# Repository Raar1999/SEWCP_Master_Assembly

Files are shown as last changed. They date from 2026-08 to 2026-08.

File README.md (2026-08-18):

# AIEF — Agent-Driven Semiconductor CAD Engineering

**An engineering pipeline that converts governed semiconductor-equipment requirements into
parametric Fusion 360 designs, verifies the resulting geometry against the requirement from the
model Fusion actually built, and iterates through failure-recovery loops before release.**

The demonstration hardware is **SEWCP** — a 300 mm bipolar electrostatic chuck pedestal for
RF-biased plasma process equipment.

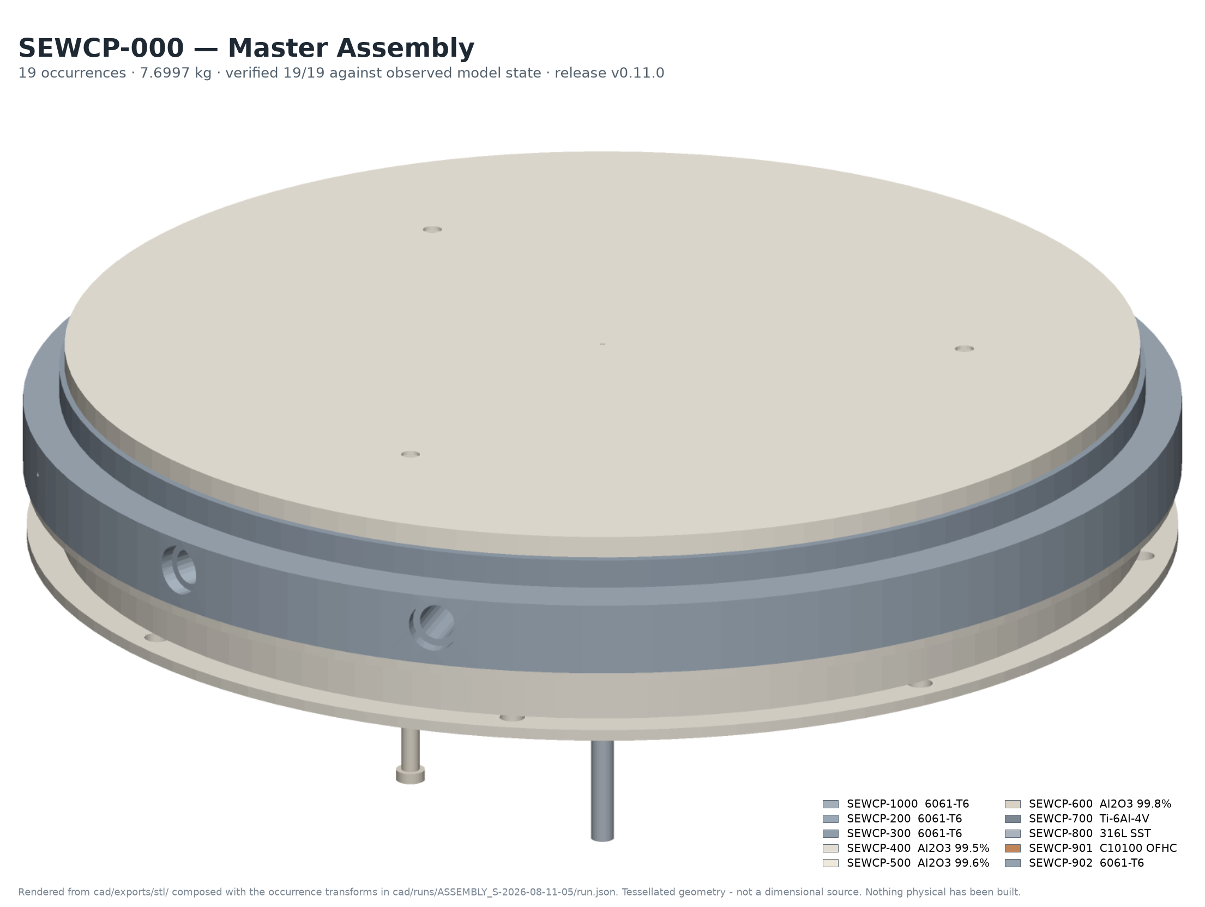
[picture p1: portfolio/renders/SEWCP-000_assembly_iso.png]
SEWCP-000 master assembly — shaded isometric of the 19-occurrence pedestal


<sub>*SEWCP-000 master assembly. Rendered from the released STL exports composed with the
occurrence transforms in `cad/runs/ASSEMBLY_S-2026-08-11-05/run.json` — every placement
reconciled against the bounding box Fusion actually observed before it was drawn. Tessellated
geometry, not a dimensional source.*</sub>

| | | | |
|---|---|---|---|
| **9** components specified | **10** part designs verified | **19** assembly occurrences | **19 / 19** system verification |
| **11** drawings / **14** sheets | **79** dimensions, **0** unsourced | **61** deliverables, digest-registered | **895** tests pass |
| **36** CAD runs tracked — **18 of them failures** | **5** independent QA rounds, **4** `NOT CLEARED` | **`v0.11.0`** released | **0 of 91** hardware requirements physically verified |

> **Read this before anything else.** The digital release is complete and reproduces from a clean
> clone. **Nothing physical has been built or measured**, and one defect is open against the
> design itself — `ECR-D-016`, the Support Ring isolation joint does not close. **Do not build to
> this baseline.** Details in [Physical qualification boundary](#physical-qualification-boundary).

**Start here:** [Recruiter overview](docs/RECRUITER_OVERVIEW.md) ·
[Architecture](docs/ARCHITECTURE.md) · [How it failed and recovered](docs/FAILURE_RECOVERY.md) ·
[Verification](docs/VERIFICATION.md) · [Independent QA](docs/QA.md)

---

## What I built

- A **Fusion 360 add-in and file-queue protocol** — 32 operations — that drives the modeller and
  reports back **what it observed**, not that the call succeeded. Fusion has no external
  automation API; code inside its own process is the only supported route.
- An **observation-based verification layer**: three independent verifiers (geometry, interface,
  constraint) that read the live model and score it against requirement-derived acceptance
  criteria. **No verifier reads whether the CAD command executed.**
- A **bounded failure-recovery loop** with root-cause classification by owning layer,
  digest-enforced no-blind-retry, capped attempts, and a document lifecycle where a design is
  **saved only on verified PASS**.
- **AIEF**, the governance framework around it: 13 laws, 12 role contracts, 25 validation rules,
  a six-stage compiler, a hash-chained ledger, and 8 standing checks that *compute* the
  properties the documents claim.
- The **SEWCP engineering specification** — Volumes 00–09, 137 numbered component requirements,
  frozen — and the CAD, drawings, BOM and analyses produced under it.

## The core idea

> **A CAD operation succeeding is not evidence that it worked.**

`extrude(...)` returning OK means Fusion accepted the operation. It says nothing about whether
the resulting solid satisfies the requirement. So three facts are kept apart and never merged:

| Fact | Reported by |
|---|---|
| An agent **requested** an operation | the orchestrator |
| Fusion **performed** it | Fusion, about its own work |
| The model **satisfies** the requirement | an independent verifier reading observed state |

Only the third is acceptance. Everything else is a claim.

## How it works

```
  spec/**  frozen, hash-registered
     │  requirements → design solution → operation sequence
     ▼
  CAD bridge  ──── file queue ────►  Fusion 360 + AIEF_CAD_Bridge add-in
     ▲                                          │
     │                           OBSERVED model state — extents, volume, mass,
     │                           material, parameters, sketches, planes, features
     │                                          ▼
     │                              independent verification
     │                               ╱                    ╲
     └── repair ◄── diagnose ◄── FAIL                    PASS ──► save · export
         (bounded)                  ╲                              draw · release
                                     └─► escalate (ECR)
```

Diagram: [`docs/assets/architecture.svg`](docs/assets/architecture.svg) · full detail:
[`docs/ARCHITECTURE.md`](docs/ARCHITECTURE.md).

## SEWCP demonstration

| | |
|---|---|
| Wafer | 300 mm × 775 µm |
| Chucking | Coulombic, bipolar, ±500 to ±2000 VDC |
| Wafer plane above Datum A | 55.920 ± 0.150 mm |
| Wafer temperature | 20–150 °C, ±2.0 °C across Ø300 |
| Coolant | 4 L/min, Re ≈ 8,300, 3 kW capacity |
| Heater | 2 zones, 2000 W |
| RF bias | 13.56 MHz, ≤ 1000 W |

Nine specified components — cooling plate, heater plate, ceramic support ring, electrostatic
chuck, lift pins, alignment pins, vacuum port, RF feedthrough bracket, temperature sensor bracket
— realised as ten part designs and one master assembly. The Base Plate `SEWCP-100` is frozen and
out of scope.

## Results

| Item | Result | Computed by |
|---|---|---|
| Gate `LC-M04-EXIT` | **PASS** C1–C7 | `python -m aief_gate` |
| Feature clearance, `spec/00` §3.2 | **PASS**, pair by pair | `python -m aief_clearance` |
| Parameter master | **105** derived | `python -m aief_params check` |
| Approval chains | **CLEAN** | `python -m aief_approval verify` |
| Deliverables | **61 registered, 61 reproduce, 0 unregistered** | `python -m aief_deliverables` |
| Freeze registry | **31 of 31 verify** | `V-24` |
| Boot step B2a, core integrity | **75 / 75**, independently recomputed | `python -m aief_stage6` |
| System interfaces | **12 / 12** | `cad/runs/SYSTEM_INTERFACES.json` |
| Assembly | **19 occurrences**, PASS, 7.6997 kg | `cad/runs/ASSEMBLY_S-2026-08-11-05/` |
| Final system verification | **19 / 19** | `cad/runs/FINAL_SYSTEM_VERIFICATION.json` |
| Tests | **895 local · 843 from a clean clone**, 0 fail | `pytest tests/` |

Every figure above is measured at the release commit `cad6ced6`. Two standing checks exit non-zero
**and are meant to**: `aief_analysis`, because `ECR-D-016` does not close, and `aief_exec check`,
which reports three open exec-layer conditions of its own. A check reporting PASS on an open
defect would itself be the defect.

> **This file is a governed deliverable, and rewriting it is a recorded act.** `README.md` is
> pinned by DC-1 in a result record, so the portfolio rewrite moved its digest and `X-06` — the
> drift detector — reported the record STALE. That is the mechanism working. It was answered the
> way the architecture prescribes: **by supersession, never by mutation.** `R-031` republishes
> the digest, seals `R-030` at the state it now stands at, and `R-030` itself is preserved.
> [`docs/DOCUMENTATION_FINDINGS.md`](docs/DOCUMENTATION_FINDINGS.md) §6.

## Engineering failure → recovery → verification

Two M6 hanger taps in the cooling plate. **Eight operations dispatched, eight executed, zero
Fusion errors.** A clean run by any normal measure of CAD automation.

It failed:

```
ACC-VOL   body:CP_BODY.volume_mm3   requirement CP-HANGER-TAP
expected  1479108.9
observed  1479282.6100163697
detail    delta 173.71 exceeds tolerance 1
```

The taps were breaking into the outer thermal-choke slots, so they removed 504.8 mm³ instead of
678.6 mm³. The bounded loop re-dispatched twice, made no progress, and **escalated rather than
degrading into a pass**. The failure disposition tried to discard the document and was *refused
by contract* — `a saved design is never discarded by recovery` — and reverted instead.

Then the finding that justifies the whole architecture: a feasibility sweep proved **no compliant
position existed anywhere inside the placement window the specification itself had given.** The
requirement was wrong, not the model. Corrected placement ruled, cleared against nine
neighbouring features, specification rows re-issued under approval, re-run — **PASS on the first
attempt, observed volume within 0.04 mm³**, and only then was the document saved.

Elapsed: **5 min 13 s**. Full trace, plus a second case:
[`docs/FAILURE_RECOVERY.md`](docs/FAILURE_RECOVERY.md).

The repository tracks **36 CAD runs, 18 PASS and 18 FAIL.** The failures are committed on
purpose — a record containing only successes has not shown you its verification working.

## Independent QA

**LAW-05: no role verifies its own output.** Independence is supplied by a **cold-context
session** that reconstructs every fact from the repository, recomputes without importing the code
under audit, writes no repository file, and returns a verdict the repairing session did not
choose.

Five rounds ran against this release. **Four returned `NOT CLEARED`**, and each found a real
defect in a repair that looked complete — including a ruling enforced only on a non-canonical
code path, which survived all 846 tests, and a check written to end a recurring defect that did
not catch that defect.

Two of their recomputations contradicted the repository and were right: the deliverables were not
byte-identical to the generation root, and the suite did not pass from a clean clone.

And the finding that is not closed: **four consecutive repair sessions each introduced a defect
of the class they were repairing** (`OI-V-17`). Recorded, not quietly repaired.

[`docs/QA.md`](docs/QA.md).

## Engineering deliverables

61 files, 4,995,097 bytes, every digest registered in [`cad/DELIVERABLES.md`](cad/DELIVERABLES.md)
and checked **both directions**.

| | |
|---|---|
| Neutral geometry | **11 STEP** — 10 parts + the master assembly — `cad/exports/step/` |
| Tessellated | **10 STL** — `cad/exports/stl/` |
| Drawings | **11 documents / 14 sheets** — SVG + PDF, with a provenance sidecar naming the source of **every one of 79 dimensions** — `drawings/` |
| BOM | indentured Rev A, cross-checked four ways — `cad/bom/` |

The parametric `.f3d` is deliberately **not** here: `SEDEP-PMP-002` §3.1 places the parametric
source of record in Fusion cloud versioning and git holds the neutral record.
[`docs/DELIVERABLES.md`](docs/DELIVERABLES.md).

## Architecture

| Layer | What it holds |
|---|---|
| **Specification** | `spec/` — Volumes 00–09, frozen and hash-registered; 137 numbered component requirements |
| **Agents** | `src/aief_cad/agents.py` + `.ai/core/agents/` — domain-bounded contributions; 12 role contracts |
| **CAD bridge** | `src/aief_cad/bridge/` + `fusion_addin/AIEF_CAD_Bridge/` — file-queue transport, 32 operations |
| **Observation** | `src/aief_cad/observe.py` — *absence is represented as absence* |
| **Verification** | `src/aief_cad/verify/` — geometry · interface · constraint |
| **Recovery** | `src/aief_cad/loop.py` — classify, repair bounded, or escalate |
| **Framework** | `framework/` + `.ai/` — laws, gates, approvals, hash-chained ledger, six-stage compiler |
| **Standing checks** | `src/` — eight packages that compute what the documents claim |

[`docs/ARCHITECTURE.md`](docs/ARCHITECTURE.md).

## Repository structure

```
spec/            frozen engineering specification, Volumes 00–09
implementation/  per-component requirement packages (the executable input)
src/             aief_cad, aief_gate, aief_clearance, aief_params, aief_approval,
                 aief_deliverables, aief_register, aief_analysis, aief_exec,
                 aief_stage6, aief_draw, sedep
fusion_addin/    AIEF_CAD_Bridge — the Fusion 360 add-in
cad/             runs (tracked evidence, failures included), exports, bom, bridge
drawings/        generator, definitions, released SVG + PDF + provenance sidecars
analysis/        tolerance stack, thermal, structural, electrical/RF, flow
framework/  .ai/ AIEF — laws, roles, gates, ledger, validation, compiler output
tests/           895 tests
docs/            portfolio and presentation layer (this pass)
```

## Reproducing the system

```bash
git clone https://github.com/Raar1999/SEWCP_Master_Assembly.git
cd SEWCP_Master_Assembly
python -m venv .venv && . .venv/Scripts/activate     # Windows; bin/activate on POSIX
pip install -r requirements.txt

PYTHONPATH=src python -m aief_gate            # LC-M04 CAD-READY: YES              exit 0
PYTHONPATH=src python -m aief_clearance       # CLEARANCE OK                       exit 0
PYTHONPATH=src python -m aief_params check    # PARAMETERS OK  105                 exit 0
PYTHONPATH=src python -m aief_approval verify # APPROVAL CHAINS OK                 exit 0
PYTHONPATH=src python -m aief_deliverables    # 61 registered, 61 reproduce        exit 0
PYTHONPATH=src python -m aief_register        # REGISTERS OK                       exit 0
PYTHONPATH=src python -m pytest tests/ -q     # 843 passed, 52 skipped, 0 failed
PYTHONPATH=src python -m aief_analysis        # 4 of 5 FAIL — ECR-D-016            exit 1
```

**These are the numbers a clone actually produces**, measured by cloning this repository from
GitHub and running the battery against it — not the numbers from the author's machine.

The 52 skips measure token budgets through two normative tokenizer families whose artifacts are
third-party binaries and are not tracked. Nothing estimates in their absence — the governing rule
makes absence **block** rather than estimate — so they skip rather than guess. Provision both in
`build/stage6/tokenizer_artifacts/` and the suite runs **894 passed, 1 skipped**; the last skip
needs `build/stage6/detcheck/`, which is gitignored and which no code here creates, so it is
unreachable from a clone by any route.

| Family | File | Raw-octet SHA-256 pinned in `core/MANIFEST.lock` |
|---|---|---|
| TF-1 | `cl100k_base.tiktoken` | `223921b76ee99bde995b7ff738513eef100fb51d18c93597a113bcffe865b2a7` |
| TF-2 | `spiece.model` (T5 SentencePiece) | `d60acb128cf7b7f2536e8f38a5b18a05535c9e14c7a355904270e15b0945ea86` |

With a sibling `TRUST_ON_FIRST_USE.json` present, **a digest mismatch is a loud failure and the
measurement is refused** — never a silent re-pin.

**This reproducibility gap was itself a defect, and it was found the only way it could be.** These
tests once *failed* on a clone while passing at the desk, so the README claimed a reproducibility
that had never been tested from outside. Recorded as `OI-V-16`; the `validate` workflow now runs
the battery on GitHub's runners, where there is no author's machine to be lucky on.

**What a clone cannot reproduce at all:** the Fusion designs live in Autodesk cloud versioning, so
regenerating `cad/` needs Fusion 360 with the add-in installed. Everything else — every gate,
every digest, the drawing set, the BOM and the whole test suite — runs offline.

## Physical qualification boundary

**This repository is a design and process artifact, not a qualified product.**

| | |
|---|---|
| Numbered component requirements | **137** |
| Desk-dischargeable — design, drawing, analysis, calculation | **46** |
| **Hardware required** | **91** |
| **Verified by physical evidence today** | **0** |

No article has been built. Nothing has been measured. The four mass figures are labelled
`MODEL-PREDICTED`, never verified — the declared method is *Scale*, and a scale needs a part. The
record is [`PVR-001`](.ai/project/verification/PVR-001_Physical_Verification_Record_And_Test_Matrix.md),
and it contains **no test result**.

A model establishes geometry and the properties that follow from geometry and a density. It
establishes **nothing** about pressure drop, heat transfer coefficient, leak rate, temperature
uniformity, contact resistance, inductance, particle generation, outgassing, cycle life,
dielectric strength or dechuck behaviour.

**And one defect is open against the design itself.** Filing the creepage/clearance trace that an
open item recorded as owed found that
[**the Support Ring isolation joint does not close**](.ai/project/ecr/ECR-D-016_Support_Ring_Isolation_Joint_Does_Not_Close.md):

| | Required | Computed |
|---|---|---|
| `SR-04` clearance | ≥ 12.00 mm | **8.50 mm** — the greatest any hardware choice can offer |
| `SR-03` creepage | ≥ 20.00 mm | **14.00 mm** as modelled; 17.42 mm at best |
| `SR-02` shunt impedance at 13.56 MHz | ≥ 400 Ω | **353.94 Ω** |

One root cause: two sections of `spec/03` compute a flange gap as empty while a third puts a
6.00 mm grounded ring inside it. It is ruled, its remedy is computed, and it is **deliberately not
implemented here**, because implementing it is a specification re-baseline.
**Do not build to this baseline.**

## Release

| | |
|---|---|
| Release | **`v0.11.0`** — CAD and software complete |
| Commit | `cad6ced6`, annotated tag `v0.11.0`. **Local history diverges from `origin` by design** — see below |
| History | **Sanitized `2026-08-18`** under `ECR-D-018`: a local account name was removed from ten tracked failure records before publication. Pre-rewrite hashes resolve at [`.ai/project/HISTORY_REMAP.md`](.ai/project/HISTORY_REMAP.md). `origin/main` still stands at the pre-rewrite `f8ff028` pending an owner force-update |
| Engineering baseline | SEWCP Rev A, Volumes 00–09 — **FROZEN** |
| Framework | AIEF 1.0.0 — **FROZEN**, fifteen amendments |
| Hardware build | **BLOCKED** by `ECR-D-016` pending a Rev B baseline revision |
| Physical qualification | **NOT STARTED** |

Everything open is at [`.ai/project/OPEN_ITEMS.md`](.ai/project/OPEN_ITEMS.md) with the full record
at [`OPEN_ITEMS_REGISTER.md`](.ai/project/OPEN_ITEMS_REGISTER.md). Nothing is hidden there,
including the failures. [`docs/RELEASE.md`](docs/RELEASE.md) ·
[`CHANGELOG.md`](CHANGELOG.md).

## Navigating

| If you want to… | Go to |
|---|---|
| Understand the project in two pages | [`docs/RECRUITER_OVERVIEW.md`](docs/RECRUITER_OVERVIEW.md) |
| Work in this repository | [`ENGINEERING.md`](ENGINEERING.md) → [`.ai/BOOT.md`](.ai/BOOT.md) |
| Read the engineering baseline | [`spec/README.md`](spec/README.md) |
| Understand datums, budgets, design rules | [`spec/00_…Architecture_and_Interface_Control.md`](spec/00_SEWCP-ENG-001_Architecture_and_Interface_Control.md) |
| See engineering decisions and their alternatives | [`.ai/project/decisions/`](.ai/project/decisions/) |
| See what only hardware can settle | [`PVR-001`](.ai/project/verification/PVR-001_Physical_Verification_Record_And_Test_Matrix.md) |
| Find any document | [`INDEX.md`](INDEX.md) |
| Contribute | [`CONTRIBUTING.md`](CONTRIBUTING.md) |

## Licence

**`MIT AND CC-BY-4.0`** — dual-licensed, and which licence applies to a file is determined by its
path and by nothing else. **MIT** for software (`src/`, `tests/`, `scripts/`, `fusion_addin/`,
`drawings/defs/`, `cad/scripts/`, `*.py`); **CC-BY-4.0** for documents, engineering artifacts and
generated design data (`spec/`, `program/`, and the remaining document trees). Both full texts are
embedded so the licence survives without a network. §3 states expressly that **no patent and no
trademark licence is granted, and that the design is not qualified hardware.**
[`LICENSE`](LICENSE) is authoritative.

## Provenance

The engineering work in this repository — specification, CAD, drawings, analysis, the framework
and its tooling — was produced by an AI agent under human owner authority, with decision authority
delegated for specified runs and every delegated decision recorded as such in
[`.ai/project/decisions/`](.ai/project/decisions/). Human approvals and delegated decisions are
distinguished everywhere they appear, and **a delegated decision is never recorded as a human
approval.** Where a governing rule requires a genuinely independent party — LAW-05 — independence
is supplied by a cold-context session or the item stays open.

Repository policy, binding and in force: no AI attribution in any commit, file or document; no
`Co-authored-by` trailers; git author information is never modified; `spec/` is frozen and defects
are raised as an ECR rather than edited in place; and no engineering decision is made in a commit.
Full text: [`CONTRIBUTING.md`](CONTRIBUTING.md) §1.

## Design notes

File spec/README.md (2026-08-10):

# SEWCP — Engineering Specification Set

**Simplified Electrostatic Wafer Chuck Platform**
**Revision A — Specification Freeze Candidate · 2026-08-07**

This is the complete engineering specification for the SEWCP 300 mm electrostatic chuck platform. It is written to a level of detail sufficient for CAD to be executed directly, without design iteration.

**The Base Plate (SEWCP-100) is frozen and is not specified here. It shall not be redesigned.**

No CAD steps, no modelling instructions, and no code are contained in this set.

---

## Read This First

**Volume 00 is the parent document.** It defines the coordinate system, datums, feature clocking map, stack-up, thermal/RF/vacuum budgets, tolerance allocation, fastener schedule, master assembly sequence, and the 13 binding Design Rules. Every component volume is written against it. **Do not begin CAD from a component volume alone.**

| Vol | Document | Part No. | Component |
|-----|---|---|---|
| **00** | **[SEWCP-ENG-001](00_SEWCP-ENG-001_Architecture_and_Interface_Control.md)** | — | **Architecture & Interface Control — START HERE** |
| — | *(frozen)* | SEWCP-100 | Base Plate — **FROZEN, NOT IN SCOPE** |
| 01 | [SEWCP-ENG-002](01_SEWCP-200_Cooling_Plate.md) | SEWCP-200 | Cooling Plate |
| 02 | [SEWCP-ENG-003](02_SEWCP-300_Heater_Plate.md) | SEWCP-300 | Heater Plate (+ thermal choke) |
| 03 | [SEWCP-ENG-004](03_SEWCP-400_Chuck_Support_Ring.md) | SEWCP-400 | Chuck Support Ring |
| 04 | [SEWCP-ENG-005](04_SEWCP-500_Electrostatic_Chuck.md) | SEWCP-500 | Electrostatic Chuck |
| 05 | [SEWCP-ENG-006](05_SEWCP-600_Lift_Pins.md) | SEWCP-600 | Lift Pins |
| 06 | [SEWCP-ENG-007](06_SEWCP-700_Alignment_Pins.md) | SEWCP-700 | Alignment Pins |
| 07 | [SEWCP-ENG-008](07_SEWCP-800_Vacuum_Port.md) | SEWCP-800 | Vacuum Port Assembly |
| 08 | [SEWCP-ENG-009](08_SEWCP-900_RF_Feedthrough_Bracket.md) | SEWCP-900 | RF Feedthrough Bracket Assembly |
| 09 | [SEWCP-ENG-010](09_SEWCP-1000_Temperature_Sensor_Bracket.md) | SEWCP-1000 | Temperature Sensor Bracket |

Every component volume follows the same 14-section structure: Engineering Purpose · Functional Requirements · Mechanical Interfaces · Mating Components · Critical Dimensions · Manufacturing Method · Material · Surface Finish · Tolerances · Assembly Sequence · Failure Modes · Design Rationale · Why Semiconductor Tools Use This Design · Interview Talking Points.

---

## Platform at a Glance

| Parameter | Value |
|---|---|
| Wafer | 300 mm × 775 µm |
| Chucking | Coulombic, bipolar, ±500 to ±2000 VDC (nominal ±1500 V) |
| Clamping pressure at ±1500 V | 38.9 mbar |
| Backside gas | Helium, 5–20 Torr |
| Wafer temperature | 20–150 °C, ±2.0 °C across Ø300 |
| Wafer plane height above Datum A | **55.920 ± 0.150 mm** |
| Thermal chain, wafer to coolant | **0.122 K/W** |
| Thermal choke | **0.100 ± 0.030 K/W** (16× Ti washers) |
| Coolant | 4 L/min, Re ≈ 8,300, 3 kW capacity |
| Heater | 2 zones, 2000 W, 28.3 kW/m² uniform density |
| RF bias | 13.56 MHz, ≤1000 W, ≤1500 V peak |
| Support Ring isolation | 0.195 K/W thermal, 435 Ω at 13.56 MHz |
| Assembly He leak rate | < 1×10⁻⁹ mbar·L/s |

## Stack-Up

```
                     Ø300 WAFER (0.775)          Z = 56.695
        ═════════════════════════════════════    Z = 55.920  ← Datum F, wafer backside
          ▲ 0.020 mesa gap, He-filled
    [ SEWCP-500  ESC          Ø297 × 6.00  ]     Al₂O₃ 99.6%, bipolar
      ░░░ elastomer bond 0.40 ░░░
    [ SEWCP-300  HEATER PLATE Ø300 × 8.00  ]     6061-T6 + MI heater, 2 zones
      ▫ THERMAL CHOKE  16× Ti washers 1.50 ▫     R = 0.100 K/W  ← the key feature
    [ SEWCP-200  COOLING PLATE Ø320 × 20.00]     6061-T6, FSW-sealed channel, RF electrode
    [ SEWCP-400  SUPPORT RING  H 20.00     ]     Al₂O₃ 99.5%, lapped to fit at assembly
    ═════════════════════════════════════════    Z = 0.000  ← Datum A
      SEWCP-100  BASE PLATE  *** FROZEN ***
```

---

## The Five Decisions That Shape Everything Else

1. **The Support Ring absorbs all frozen-baseline risk (DR-1).** The Base Plate was frozen before its interface was documented. Rather than propagate that uncertainty through nine components, one ceramic ring is the sole structural interface and every other touchpoint floats with ≥ 2 mm clearance. The same part is also the electrical isolator and the assembly shim.

2. **A thermal resistance was added on purpose.** A heater bolted flat to a 3 kW chiller rises less than 1 K. The 0.100 K/W titanium-washer choke is what makes the heater an actuator instead of a parasitic load — and it dominates the thermal chain by 10×, which is the point.

3. **Paschen's law drove three mechanical requirements.** Lift pins that never leave their bore (DR-4), helium interlocked to pin position (DR-5), and RF inhibited across the pump-down transition band (DR-11). In the last case, adding clearance makes the hazard *worse*.

4. **Constraint schemes came before tolerance schemes.** Aluminium against alumina across 130 K moves 0.3–0.4 mm. Three radial-slot kinematic locators hold centre to 20 µm while imposing no constraint force; a conventional round-and-diamond dowel pair would have missed by 3×.

5. **Nothing penetrates the wafer-facing surface (DR-2).** All 24 stack fasteners install from below, which is why the coolant serpentine must be routed around a fixed fastener pattern.

---

## Status and Open Items

**Revision A is a specification freeze candidate.** Five open items are listed in Volume 00 §13. The two that gate CAD release:

- **OI-1** — Confirm the eight Frozen Baseline Assumptions (Vol 00 §2) against the actual Base Plate drawing. By DR-1, any discrepancy affects **only** the Support Ring.
- **OI-2** — Confirm Configuration A (RF-hot chuck, specified throughout) versus Configuration B (grounded chuck), which deletes the RF Feedthrough Bracket and simplifies the Support Ring. Required before Volume 08 release.

The remaining three (OI-3 thermal choke tuning, OI-4 lift pin bolt circle vs. robot envelope, OI-5 bond elastomer qualification) are qualification-phase items and do not block CAD.

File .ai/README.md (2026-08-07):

# AIEF - AI Engineering Framework

Version 1.0.0. Repository-driven, model-agnostic operating system for AI-assisted engineering projects.

> **This file is for humans. Agents never read it.** Agents enter at `BOOT.md`.

## What this is

A repository-resident operating system for AI-assisted engineering. It exists so that engineering work survives the end of a conversation: state lives in the repository, not in a model's memory, and any session on any model can resume by reading files.

## Layout

```
.ai/
  BOOT.md            entry point - agents start here
  FRAMEWORK.md       identity, version, partitions
  README.md          this file
  core/              framework - read-only, replaced wholesale on upgrade
    laws/            13 engineering laws
    agents/          5 universal role contracts
    workflows/       6 workflows covering 12 phases
    schemas/         8 artifact schemas
    profiles/        discipline profiles - only the selected one is installed
  project/           instance data - never touched by upgrade (Stage 3)
  adapters/          host bindings (Stage 4)
```

## Principles

| | |
|---|---|
| Repository is truth | No decision exists unless it is a committed file |
| Memory is never trusted | Every session boots cold from disk |
| Every session is restartable | Session is a transaction; abandonment rolls back cleanly |
| AI assists, never replaces | AI inference is the lowest precedence rank |

## Do not

Edit anything under `core/`. It is integrity-verified at boot and replaced on upgrade.
Changes are made by amending the manifest and recompiling.

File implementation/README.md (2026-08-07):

# implementation/

Per-component implementation packages. One directory per in-scope component.

> **Structure only.** All directories were created during Release 0.1 infrastructure preparation and contain placeholders. No implementation instructions exist here except the Cooling Plate CAD package, which was migrated from `cad/` unchanged.

---

## Components

| # | Directory | Part No. | Specification | WBS | Status |
|---|---|---|---|---|---|
| 01 | `01_SEWCP-200_Cooling_Plate/` | SEWCP-200 | [Vol 01](../spec/01_SEWCP-200_Cooling_Plate.md) | 3.2 | **CAD pkg Rev X1 — HOLD** |
| 02 | `02_SEWCP-300_Heater_Plate/` | SEWCP-300 | [Vol 02](../spec/02_SEWCP-300_Heater_Plate.md) | 3.4 | Not started |
| 03 | `03_SEWCP-400_Chuck_Support_Ring/` | SEWCP-400 | [Vol 03](../spec/03_SEWCP-400_Chuck_Support_Ring.md) | 3.3 | Not started |
| 04 | `04_SEWCP-500_Electrostatic_Chuck/` | SEWCP-500 | [Vol 04](../spec/04_SEWCP-500_Electrostatic_Chuck.md) | 3.5 | Not started |
| 05 | `05_SEWCP-600_Lift_Pins/` | SEWCP-600 | [Vol 05](../spec/05_SEWCP-600_Lift_Pins.md) | 3.6 | Not started |
| 06 | `06_SEWCP-700_Alignment_Pins/` | SEWCP-700 | [Vol 06](../spec/06_SEWCP-700_Alignment_Pins.md) | 3.7 | Not started |
| 07 | `07_SEWCP-800_Vacuum_Port/` | SEWCP-800 | [Vol 07](../spec/07_SEWCP-800_Vacuum_Port.md) | 3.8 | Not started |
| 08 | `08_SEWCP-900_RF_Feedthrough_Bracket/` | SEWCP-900 | [Vol 08](../spec/08_SEWCP-900_RF_Feedthrough_Bracket.md) | 3.9 | Not started |
| 09 | `09_SEWCP-1000_Temperature_Sensor_Bracket/` | SEWCP-1000 | [Vol 09](../spec/09_SEWCP-1000_Temperature_Sensor_Bracket.md) | 3.10 | Not started |

**SEWCP-100 Base Plate is frozen and out of scope.** It has no implementation directory.

---

## Naming Convention

```
<NN>_<PART-NUMBER>_<Component_Name>/
```

`NN` matches the governing specification volume number, so `implementation/` and `spec/` sort into the same order.

Component names follow the **specification** part name, not colloquial usage — e.g. `Chuck_Support_Ring`, not `Support_Ring`.

---

## Standard Sub-Structure

Every component directory contains:

| Sub-dir | Holds |
|---|---|
| `cad/` | CAD implementation package, modelling records, conformance evidence |
| `params/` | Component parameter file, Fusion user-parameter export |
| `drawings/` | Drawing sheets, redlines, check records |
| `verification/` | Dimensional conformance, inspection and analysis records |

---

## Rules

1. Nothing in this tree may introduce a dimension, interface, or material not traceable to `spec/`.
2. Discrepancies against the frozen baseline are raised as **ECR**, never resolved here.
3. Work does not begin on a component until program gate **G1** has passed and its parameter master exists.

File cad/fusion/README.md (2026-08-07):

# cad/fusion/

Local Autodesk Fusion 360 working files.

> **This directory is ignored by git.** See `.gitignore` — `*.f3d`, `*.f3z`, `*.f2d`, `*.f3b`.

---

## Why Fusion Files Are Not Tracked

Policy: **SEDEP-PMP-002 §3.1.**

> Git holds the neutral geometry record; Fusion holds the parametric one.

| Record | System of record | Rationale |
|---|---|---|
| Parametric model | **Fusion Team cloud** | Native versioning, named milestones, branching |
| Neutral geometry | **Git** (`cad/exports/step/`) | Diffable-by-hash, supplier-consumable, permanent |
| Drawings | **Git** (`drawings/`) | Released record |

Fusion binaries are large, opaque to diff, and already versioned in the cloud. Committing them produces repository bloat with no traceability benefit.

---

## Fusion Team Project Structure

The authoritative CAD hierarchy is defined in **SEDEP-PMP-002 §3**:

```
SEWCP_Master_Assembly/          [Fusion Team Project]
  00_REFERENCE/                 Frozen Base Plate, wafer, robot envelope
  01_SKELETON/                  Datum frame, Z-stack, clocking map
  02_PARTS/                     One design per part
  03_SUBASSEMBLIES/
  04_MASTER_ASSEMBLY/
  05_DRAWINGS/
  06_SIMULATION/
  07_EXPORTS/                   Mirrored to cad/exports/
```

---

## Version Correlation

Fusion version milestones are named to match git tags (`gate/G2`, `v1.0.0`) so a repository state can be tied to a CAD state.

At every gate:
1. Name the Fusion version milestone to match the git tag.
2. Export STEP to `cad/exports/step/`.
3. Commit the STEP with the tag.

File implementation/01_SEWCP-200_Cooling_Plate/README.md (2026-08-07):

# SEWCP-200 — Cooling Plate

**Component:** 01 of 09 · **Part Number:** SEWCP-200 · **WBS:** 3.2
**Status:** CAD package Rev X1 issued - ON HOLD (4 open ECR-D)

> **PLACEHOLDER.** This directory was created during Release 0.1 infrastructure
> preparation. It contains no implementation instructions and no engineering
> content. Populating it is a Phase P2 activity under WBS 3.2.

---

## Governing Specification

**FROZEN — read only.** All geometry, tolerances, materials and interfaces for
this component are defined in:

- [`spec/01_SEWCP-200_Cooling_Plate.md`](../../spec/01_SEWCP-200_Cooling_Plate.md) — component specification
- [`spec/00_SEWCP-ENG-001_Architecture_and_Interface_Control.md`](../../spec/00_SEWCP-ENG-001_Architecture_and_Interface_Control.md) — datums, clocking map, Z-stack, design rules DR-1…DR-13

No dimension, interface or material may be introduced here that is not traceable
to those documents.

---

## Directory Purpose

| Path | Holds | Status |
|---|---|---|
| `cad/` | CAD implementation package, modelling records, conformance evidence | Empty |
| `params/` | Component parameter file, Fusion user-parameter export | Empty |
| `drawings/` | Drawing sheets, redlines, check records | Empty |
| `verification/` | Dimensional conformance, inspection and analysis records | Empty |

---

## Entry Conditions

This directory is not worked until:

1. Program gate **G1** (Digital Foundation Review) has passed.
2. The parameter master for SEWCP-200 exists under `params/parts/`.
3. WBS 3.2 predecessors are complete per SEDEP-PMP-001 §3.1.

---

## Change Control

Governed by SEDEP-PMP-001 §0.1. Any discrepancy found against the frozen
specification is raised as an **ECR**, never resolved at working level.

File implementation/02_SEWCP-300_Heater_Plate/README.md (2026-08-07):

# SEWCP-300 — Heater Plate

**Component:** 02 of 09 · **Part Number:** SEWCP-300 · **WBS:** 3.4
**Status:** Not started

> **PLACEHOLDER.** This directory was created during Release 0.1 infrastructure
> preparation. It contains no implementation instructions and no engineering
> content. Populating it is a Phase P2 activity under WBS 3.4.

---

## Governing Specification

**FROZEN — read only.** All geometry, tolerances, materials and interfaces for
this component are defined in:

- [`spec/02_SEWCP-300_Heater_Plate.md`](../../spec/02_SEWCP-300_Heater_Plate.md) — component specification
- [`spec/00_SEWCP-ENG-001_Architecture_and_Interface_Control.md`](../../spec/00_SEWCP-ENG-001_Architecture_and_Interface_Control.md) — datums, clocking map, Z-stack, design rules DR-1…DR-13

No dimension, interface or material may be introduced here that is not traceable
to those documents.

---

## Directory Purpose

| Path | Holds | Status |
|---|---|---|
| `cad/` | CAD implementation package, modelling records, conformance evidence | Empty |
| `params/` | Component parameter file, Fusion user-parameter export | Empty |
| `drawings/` | Drawing sheets, redlines, check records | Empty |
| `verification/` | Dimensional conformance, inspection and analysis records | Empty |

---

## Entry Conditions

This directory is not worked until:

1. Program gate **G1** (Digital Foundation Review) has passed.
2. The parameter master for SEWCP-300 exists under `params/parts/`.
3. WBS 3.4 predecessors are complete per SEDEP-PMP-001 §3.1.

---

## Change Control

Governed by SEDEP-PMP-001 §0.1. Any discrepancy found against the frozen
specification is raised as an **ECR**, never resolved at working level.

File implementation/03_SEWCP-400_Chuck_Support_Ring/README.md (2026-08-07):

# SEWCP-400 — Chuck Support Ring

**Component:** 03 of 09 · **Part Number:** SEWCP-400 · **WBS:** 3.3
**Status:** Not started

> **PLACEHOLDER.** This directory was created during Release 0.1 infrastructure
> preparation. It contains no implementation instructions and no engineering
> content. Populating it is a Phase P2 activity under WBS 3.3.

---

## Governing Specification

**FROZEN — read only.** All geometry, tolerances, materials and interfaces for
this component are defined in:

- [`spec/03_SEWCP-400_Chuck_Support_Ring.md`](../../spec/03_SEWCP-400_Chuck_Support_Ring.md) — component specification
- [`spec/00_SEWCP-ENG-001_Architecture_and_Interface_Control.md`](../../spec/00_SEWCP-ENG-001_Architecture_and_Interface_Control.md) — datums, clocking map, Z-stack, design rules DR-1…DR-13

No dimension, interface or material may be introduced here that is not traceable
to those documents.

---

## Directory Purpose

| Path | Holds | Status |
|---|---|---|
| `cad/` | CAD implementation package, modelling records, conformance evidence | Empty |
| `params/` | Component parameter file, Fusion user-parameter export | Empty |
| `drawings/` | Drawing sheets, redlines, check records | Empty |
| `verification/` | Dimensional conformance, inspection and analysis records | Empty |

---

## Entry Conditions

This directory is not worked until:

1. Program gate **G1** (Digital Foundation Review) has passed.
2. The parameter master for SEWCP-400 exists under `params/parts/`.
3. WBS 3.3 predecessors are complete per SEDEP-PMP-001 §3.1.

---

## Change Control

Governed by SEDEP-PMP-001 §0.1. Any discrepancy found against the frozen
specification is raised as an **ECR**, never resolved at working level.

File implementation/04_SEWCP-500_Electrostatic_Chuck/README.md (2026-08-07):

# SEWCP-500 — Electrostatic Chuck

**Component:** 04 of 09 · **Part Number:** SEWCP-500 · **WBS:** 3.5
**Status:** Not started

> **PLACEHOLDER.** This directory was created during Release 0.1 infrastructure
> preparation. It contains no implementation instructions and no engineering
> content. Populating it is a Phase P2 activity under WBS 3.5.

---

## Governing Specification

**FROZEN — read only.** All geometry, tolerances, materials and interfaces for
this component are defined in:

- [`spec/04_SEWCP-500_Electrostatic_Chuck.md`](../../spec/04_SEWCP-500_Electrostatic_Chuck.md) — component specification
- [`spec/00_SEWCP-ENG-001_Architecture_and_Interface_Control.md`](../../spec/00_SEWCP-ENG-001_Architecture_and_Interface_Control.md) — datums, clocking map, Z-stack, design rules DR-1…DR-13

No dimension, interface or material may be introduced here that is not traceable
to those documents.

---

## Directory Purpose

| Path | Holds | Status |
|---|---|---|
| `cad/` | CAD implementation package, modelling records, conformance evidence | Empty |
| `params/` | Component parameter file, Fusion user-parameter export | Empty |
| `drawings/` | Drawing sheets, redlines, check records | Empty |
| `verification/` | Dimensional conformance, inspection and analysis records | Empty |

---

## Entry Conditions

This directory is not worked until:

1. Program gate **G1** (Digital Foundation Review) has passed.
2. The parameter master for SEWCP-500 exists under `params/parts/`.
3. WBS 3.5 predecessors are complete per SEDEP-PMP-001 §3.1.

---

## Change Control

Governed by SEDEP-PMP-001 §0.1. Any discrepancy found against the frozen
specification is raised as an **ECR**, never resolved at working level.

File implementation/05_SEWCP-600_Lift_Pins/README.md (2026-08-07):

# SEWCP-600 — Lift Pins

**Component:** 05 of 09 · **Part Number:** SEWCP-600 · **WBS:** 3.6
**Status:** Not started

> **PLACEHOLDER.** This directory was created during Release 0.1 infrastructure
> preparation. It contains no implementation instructions and no engineering
> content. Populating it is a Phase P2 activity under WBS 3.6.

---

## Governing Specification

**FROZEN — read only.** All geometry, tolerances, materials and interfaces for
this component are defined in:

- [`spec/05_SEWCP-600_Lift_Pins.md`](../../spec/05_SEWCP-600_Lift_Pins.md) — component specification
- [`spec/00_SEWCP-ENG-001_Architecture_and_Interface_Control.md`](../../spec/00_SEWCP-ENG-001_Architecture_and_Interface_Control.md) — datums, clocking map, Z-stack, design rules DR-1…DR-13

No dimension, interface or material may be introduced here that is not traceable
to those documents.

---

## Directory Purpose

| Path | Holds | Status |
|---|---|---|
| `cad/` | CAD implementation package, modelling records, conformance evidence | Empty |
| `params/` | Component parameter file, Fusion user-parameter export | Empty |
| `drawings/` | Drawing sheets, redlines, check records | Empty |
| `verification/` | Dimensional conformance, inspection and analysis records | Empty |

---

## Entry Conditions

This directory is not worked until:

1. Program gate **G1** (Digital Foundation Review) has passed.
2. The parameter master for SEWCP-600 exists under `params/parts/`.
3. WBS 3.6 predecessors are complete per SEDEP-PMP-001 §3.1.

---

## Change Control

Governed by SEDEP-PMP-001 §0.1. Any discrepancy found against the frozen
specification is raised as an **ECR**, never resolved at working level.

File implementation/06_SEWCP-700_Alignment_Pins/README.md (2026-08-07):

# SEWCP-700 — Alignment Pins

**Component:** 06 of 09 · **Part Number:** SEWCP-700 · **WBS:** 3.7
**Status:** Not started

> **PLACEHOLDER.** This directory was created during Release 0.1 infrastructure
> preparation. It contains no implementation instructions and no engineering
> content. Populating it is a Phase P2 activity under WBS 3.7.

---

## Governing Specification

**FROZEN — read only.** All geometry, tolerances, materials and interfaces for
this component are defined in:

- [`spec/06_SEWCP-700_Alignment_Pins.md`](../../spec/06_SEWCP-700_Alignment_Pins.md) — component specification
- [`spec/00_SEWCP-ENG-001_Architecture_and_Interface_Control.md`](../../spec/00_SEWCP-ENG-001_Architecture_and_Interface_Control.md) — datums, clocking map, Z-stack, design rules DR-1…DR-13

No dimension, interface or material may be introduced here that is not traceable
to those documents.

---

## Directory Purpose

| Path | Holds | Status |
|---|---|---|
| `cad/` | CAD implementation package, modelling records, conformance evidence | Empty |
| `params/` | Component parameter file, Fusion user-parameter export | Empty |
| `drawings/` | Drawing sheets, redlines, check records | Empty |
| `verification/` | Dimensional conformance, inspection and analysis records | Empty |

---

## Entry Conditions

This directory is not worked until:

1. Program gate **G1** (Digital Foundation Review) has passed.
2. The parameter master for SEWCP-700 exists under `params/parts/`.
3. WBS 3.7 predecessors are complete per SEDEP-PMP-001 §3.1.

---

## Change Control

Governed by SEDEP-PMP-001 §0.1. Any discrepancy found against the frozen
specification is raised as an **ECR**, never resolved at working level.

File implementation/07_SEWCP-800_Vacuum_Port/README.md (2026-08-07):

# SEWCP-800 — Vacuum Port

**Component:** 07 of 09 · **Part Number:** SEWCP-800 · **WBS:** 3.8
**Status:** Not started

> **PLACEHOLDER.** This directory was created during Release 0.1 infrastructure
> preparation. It contains no implementation instructions and no engineering
> content. Populating it is a Phase P2 activity under WBS 3.8.

---

## Governing Specification

**FROZEN — read only.** All geometry, tolerances, materials and interfaces for
this component are defined in:

- [`spec/07_SEWCP-800_Vacuum_Port.md`](../../spec/07_SEWCP-800_Vacuum_Port.md) — component specification
- [`spec/00_SEWCP-ENG-001_Architecture_and_Interface_Control.md`](../../spec/00_SEWCP-ENG-001_Architecture_and_Interface_Control.md) — datums, clocking map, Z-stack, design rules DR-1…DR-13

No dimension, interface or material may be introduced here that is not traceable
to those documents.

---

## Directory Purpose

| Path | Holds | Status |
|---|---|---|
| `cad/` | CAD implementation package, modelling records, conformance evidence | Empty |
| `params/` | Component parameter file, Fusion user-parameter export | Empty |
| `drawings/` | Drawing sheets, redlines, check records | Empty |
| `verification/` | Dimensional conformance, inspection and analysis records | Empty |

---

## Entry Conditions

This directory is not worked until:

1. Program gate **G1** (Digital Foundation Review) has passed.
2. The parameter master for SEWCP-800 exists under `params/parts/`.
3. WBS 3.8 predecessors are complete per SEDEP-PMP-001 §3.1.

---

## Change Control

Governed by SEDEP-PMP-001 §0.1. Any discrepancy found against the frozen
specification is raised as an **ECR**, never resolved at working level.

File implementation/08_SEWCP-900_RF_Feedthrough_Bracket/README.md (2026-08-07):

# SEWCP-900 — RF Feedthrough Bracket

**Component:** 08 of 09 · **Part Number:** SEWCP-900 · **WBS:** 3.9
**Status:** Not started

> **PLACEHOLDER.** This directory was created during Release 0.1 infrastructure
> preparation. It contains no implementation instructions and no engineering
> content. Populating it is a Phase P2 activity under WBS 3.9.

---

## Governing Specification

**FROZEN — read only.** All geometry, tolerances, materials and interfaces for
this component are defined in:

- [`spec/08_SEWCP-900_RF_Feedthrough_Bracket.md`](../../spec/08_SEWCP-900_RF_Feedthrough_Bracket.md) — component specification
- [`spec/00_SEWCP-ENG-001_Architecture_and_Interface_Control.md`](../../spec/00_SEWCP-ENG-001_Architecture_and_Interface_Control.md) — datums, clocking map, Z-stack, design rules DR-1…DR-13

No dimension, interface or material may be introduced here that is not traceable
to those documents.

---

## Directory Purpose

| Path | Holds | Status |
|---|---|---|
| `cad/` | CAD implementation package, modelling records, conformance evidence | Empty |
| `params/` | Component parameter file, Fusion user-parameter export | Empty |
| `drawings/` | Drawing sheets, redlines, check records | Empty |
| `verification/` | Dimensional conformance, inspection and analysis records | Empty |

---

## Entry Conditions

This directory is not worked until:

1. Program gate **G1** (Digital Foundation Review) has passed.
2. The parameter master for SEWCP-900 exists under `params/parts/`.
3. WBS 3.9 predecessors are complete per SEDEP-PMP-001 §3.1.

---

## Change Control

Governed by SEDEP-PMP-001 §0.1. Any discrepancy found against the frozen
specification is raised as an **ECR**, never resolved at working level.

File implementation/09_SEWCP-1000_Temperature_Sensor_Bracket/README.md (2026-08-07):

# SEWCP-1000 — Temperature Sensor Bracket

**Component:** 09 of 09 · **Part Number:** SEWCP-1000 · **WBS:** 3.10
**Status:** Not started

> **PLACEHOLDER.** This directory was created during Release 0.1 infrastructure
> preparation. It contains no implementation instructions and no engineering
> content. Populating it is a Phase P2 activity under WBS 3.10.

---

## Governing Specification

**FROZEN — read only.** All geometry, tolerances, materials and interfaces for
this component are defined in:

- [`spec/09_SEWCP-1000_Temperature_Sensor_Bracket.md`](../../spec/09_SEWCP-1000_Temperature_Sensor_Bracket.md) — component specification
- [`spec/00_SEWCP-ENG-001_Architecture_and_Interface_Control.md`](../../spec/00_SEWCP-ENG-001_Architecture_and_Interface_Control.md) — datums, clocking map, Z-stack, design rules DR-1…DR-13

No dimension, interface or material may be introduced here that is not traceable
to those documents.

---

## Directory Purpose

| Path | Holds | Status |
|---|---|---|
| `cad/` | CAD implementation package, modelling records, conformance evidence | Empty |
| `params/` | Component parameter file, Fusion user-parameter export | Empty |
| `drawings/` | Drawing sheets, redlines, check records | Empty |
| `verification/` | Dimensional conformance, inspection and analysis records | Empty |

---

## Entry Conditions

This directory is not worked until:

1. Program gate **G1** (Digital Foundation Review) has passed.
2. The parameter master for SEWCP-1000 exists under `params/parts/`.
3. WBS 3.10 predecessors are complete per SEDEP-PMP-001 §3.1.

---

## Change Control

Governed by SEDEP-PMP-001 §0.1. Any discrepancy found against the frozen
specification is raised as an **ECR**, never resolved at working level.

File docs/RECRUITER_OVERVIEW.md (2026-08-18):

# AIEF / SEWCP — Recruiter Overview

*Two pages. Every figure is computed by a command named beside it, at release `v0.11.0`,
commit `cad6ced6`.*

---

## What

**An agent-driven engineering system that turns a governed semiconductor-equipment
specification into parametric Fusion 360 CAD, reads the resulting model back out of Fusion, and
verifies the observed geometry against the requirement before anything is saved or released.**

The demonstration hardware is **SEWCP** — a 300 mm bipolar electrostatic chuck pedestal for
RF-biased plasma process equipment. Cooling plate, heater plate, ceramic support ring,
electrostatic chuck, lift pins, alignment pins, vacuum port, RF feedthrough, sensor bracket.

## Why it exists

An LLM can emit CAD API calls, and Fusion will happily execute them. **Execution success is not
engineering correctness** — it only means Fusion accepted the operation. The gap between those
two things is where design defects live.

AIEF closes that gap: after every run it queries the live model for extents, volume, mass,
material, parameters, sketches, planes and the feature list, and compares the *observed* values
to the frozen requirement. A run that executes cleanly and produces the wrong solid **fails**.

## How it works

```
governed requirements → design solution → command sequence → Fusion 360
        ↑                                                        │
        │                                              observed model state
    repair / re-run                                              │
        ↑                                                        ▼
      FAIL ←──────────────── independent verification ────────→ PASS → save + release
```

Full detail: [`ARCHITECTURE.md`](ARCHITECTURE.md).

## Result — verified figures

| | |
|---|---|
| Components specified, frozen Rev A | **9** (137 numbered requirements) |
| Part designs modelled and verified | **10** |
| Master assembly | **19 occurrences**, 7.6997 kg |
| Final system verification | **19 / 19** |
| System interfaces | **12 / 12** |
| Drawings | **11 documents / 14 sheets**, **79 dimensions, 0 unsourced** |
| Registered deliverables | **61 files**, 4,995,097 bytes, digest-checked both directions |
| Test suite | **895 pass** locally · **843 pass, 52 skip, 0 fail** from a clean clone |
| Standing checks | 7 exit 0; 2 exit 1 **by design**, on defects that are real |
| Independent QA rounds | **5**, cold-context; 4 returned `NOT CLEARED` |
| Tracked CAD runs | **36** — 18 PASS and **18 FAIL, kept in the repository** |
| **Physical qualification** | **0 of 91 hardware-verifiable requirements. Not started.** |

## Key technology

Python 3.11 · Autodesk Fusion 360 API and a custom add-in (the CAD bridge) · agent role
orchestration under a file-based governance framework · observation-based geometry verification
· SHA-256 digest provenance and a hash-chained ledger · deterministic SVG/PDF drawing generation
· Git, GitHub Actions CI, digest-registered release manifests.

## Key differentiator

**Design → Execute → Observe → Verify → Repair.**

Most CAD automation stops at *Execute*. This system treats the executed command as an unproven
claim and the observed model as the only evidence. Concretely: two Ø6 hanger taps were cut at
radius **137.000 mm** instead of the ruled **150.000 mm**. Every Fusion operation returned OK.
The run **failed** — because the observed solid retained 173.71 mm³ more material than the
requirement allowed, against a 1 mm³ tolerance. That is
[the whole argument](FAILURE_RECOVERY.md), in one measurement.

## What I actually engineered

- The **CAD bridge**: a Fusion 360 add-in exposing a 16-operation vocabulary + an extension
  module, driven over a file queue, that returns *observed* state rather than acknowledgements.
- The **verification layer**: three independent verifiers (geometry, interface, constraint) that
  score a run from observed model state against requirement-derived acceptance criteria.
- The **document lifecycle**: identity without persistence, first-save only on verified PASS,
  and an explicit failure disposition — which is why the tree carries no blank orphan designs.
- The **governance framework (AIEF)**: 13 laws, 12 role contracts, 25 validation rules, a
  six-stage compiler, a hash-chained ledger, and eight standing checks that compute the
  properties the documents claim.
- The **engineering specification** and the **CAD, drawings, BOM and analyses** produced under it.

## Limitation — stated first, not buried

**Digital release is complete. Physical qualification is not started.** No article has been
built, nothing has been measured, and 91 of the 137 requirements need hardware. Four mass
figures are labelled `MODEL-PREDICTED`, never verified.

**One defect is open against the design itself.** `ECR-D-016` — the Support Ring isolation joint
does not close: creepage 14.00 mm against 20.00 mm required, clearance 8.50 mm against 12.00 mm,
shunt impedance 353.94 Ω against 400 Ω. It was found by a standing check, it is ruled, its
remedy is computed, and it is deliberately **not** implemented, because implementing it is a
specification re-baseline. **Do not build to this baseline.**

Both facts are in the release tag message, the first screen of the README, and
[`RELEASE.md`](RELEASE.md). A design system that hides its open defects is not one I would
want to be judged on.

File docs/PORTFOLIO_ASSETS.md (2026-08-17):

# Portfolio Asset Register

*Every asset listed below **exists in this repository** and was inspected during the portfolio
pass. Nothing here is fabricated, and no stock or generic image is substituted for a project
visual. §3 lists what does not exist and must be captured manually.*

---

## 1 · What exists

**Two shaded 3-D renders**, generated in-repository by `scripts/render_assembly.py` from the
released STL exports composed with the occurrence transforms in the assembly run record. They
are **derived from repository evidence, not drawn**: the script reconciles every occurrence's
transformed mesh bounding box against the bounding box Fusion actually observed, prints the
deviation, and `--strict` refuses to render past tolerance. Reproduce with:

```bash
python scripts/render_assembly.py --strict
```

**Reconciliation, as measured:** 18 of 19 occurrences agree to **≤ 0.072 mm** — inward chord
error from tessellation. `SEWCP-902_SADDLE` is tessellated at 340 triangles and deviates up to
**3.864 mm** on two faces of its bounding box, entirely inward, while its mesh volume agrees with
the observed solid to **0.018 %**. Applying `z_axis_scale = −1.0` to the three inverted alignment
pins is the difference between **0.0000 mm** and **9.5000 mm** on those three — the record carries
that field, and the render reads it.

Also **14 generated drawing sheets** — SVG and PDF, produced deterministically by
`drawings/generate.py`, every dimension carrying a provenance entry. These are the released
engineering record; the renders are presentation.

## 2 · Asset register

| # | Purpose | Asset | Location | Recommended caption |
|---:|---|---|---|---|
| 1 | **Hero — shaded assembly** | `SEWCP-000_assembly_iso.png` | `portfolio/renders/` | *"SEWCP-000 master assembly — 300 mm bipolar electrostatic chuck pedestal. 19 occurrences, 7.6997 kg, verified 19/19 against observed model state."* |
| 2 | **Exploded assembly** | `SEWCP-000_assembly_exploded.png` | `portfolio/renders/` | *"The stack, separated along +Z: ceramic support ring, cooling plate with its coolant stubs and RF strap, heater plate, ESC puck, with lift pins and alignment pins through. Every placement is as recorded; only the separation is added."* |
| 3 | **Assembly section + BOM** | `SEWCP-000-DRW-001_Sh2.svg` (also `.pdf`) | `drawings/assembly/` | *"Master assembly, section elevation — Datum A to wafer plane at 55.920 mm, with the indentured BOM. Every dimension traced to a parameter or a specification clause."* |
| 4 | **Assembly plan / occurrence map** | `SEWCP-000-DRW-001_Sh1.svg` | `drawings/assembly/` | *"Plan view with balloons and the observed occurrence table — the 19 placements read back out of Fusion, not asserted."* |
| 5 | **Joint and fastener schedule** | `SEWCP-000-DRW-001_Sh3.svg` | `drawings/assembly/` | *"Joint / fastener schedule — torque and stack-up per joint, transcribed verbatim from `spec/00` §9."* |
| 6 | **Cooling plate** | `SEWCP-200-DRW-001_Sh1.svg` | `drawings/parts/SEWCP-200/` | *"Cooling Plate — Ø320 × 20 mm, 6061-T6. Top and Section A-A. Bifilar counterflow coolant channel routed by derivation around every keep-out; coolant in 255° / out 285°."* |
| 7 | **Cooling plate — surface treatment** | `SEWCP-200-DRW-001_Sh2.svg` | `drawings/parts/SEWCP-200/` | *"Bottom- and top-face mask map — hard anodise except masks, including the RF land."* |
| 8 | **Heater plate** | `SEWCP-300-DRW-001_Sh1.svg` | `drawings/parts/SEWCP-300/` | *"Heater Plate — Ø300 × 8 mm. Two-zone spiral element grooves, generated by exact keep-out projection and arc-chain compression."* |
| 9 | **Support ring — the open defect** | `SEWCP-400-DRW-001_Sh1.svg` | `drawings/parts/SEWCP-400/` | *"Chuck Support Ring, Al₂O₃ 99.5 %. This is the part `ECR-D-016` is open against: the isolation joint does not close on frozen dimensions — creepage 14.00 mm against 20.00 required."* |
| 10 | **Electrostatic chuck** | `SEWCP-500-DRW-001_Sh1.svg` | `drawings/parts/SEWCP-500/` | *"ESC Puck — Ø297 × 6 mm, Al₂O₃ 99.6 %, bipolar Coulombic, lapped top with mesa process."* |
| 11 | **Component detail — precision fit** | `SEWCP-700-DRW-001_Sh1.svg` | `drawings/parts/SEWCP-700/` | *"Alignment Pin, Ti-6Al-4V — Ø6.000 boss, 2.5 ±0.05 protrusion into a 3.00 slot. Verified against the mating feature: `IF-AP-SR` gap +0.050, computed from observed model state."* |
| 12 | **RF feedthrough** | `SEWCP-901-DRW-001_Sh1.svg` | `drawings/parts/SEWCP-901/` | *"RF Strap, C10100 OFHC — installed form and flat pattern, 180.0 ±2.0 developed. 13.56 MHz bias path."* |
| 13 | **Assembly interface detail** | `SEWCP-902-DRW-001_Sh1.svg` | `drawings/parts/SEWCP-902/` | *"Saddle — plate-hung hanger, Rev B. The architecture that replaced the original after `ECR-Q-012`; 8.0 mm minimum to ground."* |
| 14 | **BOM** | `SEWCP-000_BOM_RevA.csv`, and the BOM table rendered on assembly sheet 2 | `cad/bom/` | *"Indentured BOM Rev A, cross-checked four ways against the assembly run record. Each line states its CAD state — 10 verified models, 13 spec-only."* |
| 15 | **Architecture diagram** | `docs/assets/architecture.svg` | `docs/assets/` | *"Requirements → agent → CAD bridge → Fusion → observed model → verification → PASS or repair. The observation arrow is the whole design."* |
| 16 | **Architecture diagram, in-page** | Mermaid flowchart | `docs/ARCHITECTURE.md` §1 | renders natively on GitHub in both themes; same content as #15 |

### Notes on use

- **The renders are presentation; the drawings are the record.** A number read off a render has
  been read off a tessellation. Cite the drawing or the run record for any dimension.
- **SVG over PDF for the web.** GitHub renders repository SVGs inline; the PDFs are the release
  record. Both are byte-identical to what `drawings/generate.py` produces.
- The drawing sheets are **white-background line drawings**. They read correctly in a light theme
  and remain legible in a dark one.
- **Do not crop a title block off** a drawing used as a portfolio visual. The title block carries
  the revision and date, and a drawing without it looks like an illustration rather than a
  released document.
- The renders' caption bar already carries *"Nothing physical has been built."* **Keep it.** A
  shaded render is the single most likely artifact in this repository to be mistaken for a
  photograph of hardware.

---

## 3 · What still requires manual capture

**Nothing here was fabricated, and nothing below is blocking.** The two highest-priority visuals
— the shaded hero and the exploded view — were open at the end of the portfolio pass and are now
generated from repository evidence (§1). What remains needs either a Fusion licence, a live
session, or a GitHub state this repository cannot set for itself.

| # | Wanted | How to obtain | Priority |
|---:|---|---|---|
| 1 | **Failing-run / passing-run comparison** | a formatted excerpt of `cad/runs/RUN-20260811T224345-ff189f/run.json` beside `RUN-20260811T224915-001c51/run.json` — needs no Fusion and is reproducible from the repository today; *or* a terminal capture of `python -m aief_cad run …` against a live session | **highest** — it is the project's actual argument, and it is currently prose where it could be an image |
| 2 | **BRep-accurate render** | the current renders are from STL tessellations. A viewer that reads `cad/exports/step/SEWCP-000_MASTER_ASSEMBLY.step` directly would render exact surfaces and remove the 3.864 mm saddle deviation noted in §1 | medium — visual polish, no new information |
| 3 | **Screenshot of the Fusion add-in running** | Fusion → UTILITIES → ADD-INS → `AIEF_CAD_Bridge`. Shows the one genuinely human-gated step in the whole pipeline | medium |
| 4 | **CI badge / green Actions run** | requires the repository to be public, or a screenshot of the Actions tab | medium — see [`DOCUMENTATION_FINDINGS.md`](DOCUMENTATION_FINDINGS.md) §1 |
| 5 | **Fusion-native shaded render with edges** | Fusion 360 in-canvas render of `SEWCP-000_MASTER_ASSEMBLY`, isometric, ≥ 2000 px | low — the generated render already covers this use |
| 6 | **Dark-theme drawing sheet** | re-render an SVG with inverted stroke/fill, or screenshot the PDF on a dark page | low |

Destination for anything captured: `portfolio/renders/`. Adding image files there is a portfolio
action and changes no engineering artifact.

**Status: the portfolio has a hero.** It is not a photograph and does not pretend to be one, and
the remaining gaps are named above rather than papered over.

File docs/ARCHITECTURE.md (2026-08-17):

# Architecture

*How a governed requirement becomes verified CAD. Terminology below is the repository's own —
every named module, file and check exists and can be run.*

---

## 0 · The one principle

> **A CAD operation succeeding is not evidence that it worked.**

`fusion.extrude(...)` returning OK means Fusion accepted the operation. It says nothing about
whether the resulting solid satisfies the requirement. The architecture is built to keep three
facts apart that most automation merges into one:

| Fact | Who reports it | Where it lives |
|---|---|---|
| An agent **requested** an operation | the orchestrator | `Command` |
| Fusion **performed** it | Fusion, about its own work | `Observation.executed` |
| The model **satisfies** the requirement | an independent verifier | `verify.Verdict` |

`src/aief_cad/bridge/protocol.py` states this as its contract: *"`executed` is reported by the
party that did the work, so it is evidence for the second fact and for nothing else."* And
`src/aief_cad/verify/__init__.py` enforces it: **no verifier reads `Observation.executed`.**

---

## 1 · The loop

```mermaid
flowchart TD
    R["GOVERNED REQUIREMENTS<br/><code>spec/**</code> — frozen, hash-registered"]
    A["DESIGN AGENTS<br/>domain-bounded reasoning"]
    S["DESIGN SOLUTION<br/>what should be built"]
    O["OPERATION SEQUENCE<br/>bounded CAD vocabulary"]
    B["CAD BRIDGE<br/>file queue + Fusion add-in"]
    F["FUSION 360<br/>executes one operation"]
    M["OBSERVED MODEL STATE<br/>extents · volume · mass · material<br/>parameters · sketches · planes · features"]
    V{"INDEPENDENT VERIFICATION<br/>geometry · interface · constraint"}
    P["PASS → save document<br/>export · draw · release"]
    D["DIAGNOSE<br/>requirement · evidence · area<br/>cause · correction"]
    X["REPAIR<br/>bounded, digest-checked"]
    E["ESCALATE<br/>engineering decision / ECR"]

    R --> A --> S --> O --> B --> F --> M --> V
    V -- PASS --> P
    V -- FAIL --> D
    D -- repairable --> X --> B
    D -- not repairable --> E
```

The **observation arrow is the whole design**. Everything downstream of `M` reads what Fusion
reported about the model, never what the driver believed it had asked for.

---

## 2 · Layers

### 2.1 Requirements layer — `spec/**`, `implementation/**`

`spec/` holds the SEWCP engineering specification, Volumes 00–09, **frozen** and registered by
hash in `.ai/project/FROZEN.md` (31 of 31 verify). Volume 00 is the parent: coordinate system,
datums, feature clocking map, Z stack-up, thermal/RF/vacuum budgets, tolerance allocation,
fastener schedule and 13 binding Design Rules. Volumes 01–09 carry **137 numbered component
requirements**.

`implementation/<n>_<part>/requirements/*.requirements.json` is the executable form: a
**requirement package** describing *an engineering problem*, not a CAD model. Per
`requirements.py`, a package "may describe a heat exchanger plate, a mounting bracket, a vacuum
component, a fixture" — the CAD layer holds no SEWCP knowledge.

A frozen document is never edited to fix a defect. A defect becomes an **ECR** (LAW-02).
24 ECR records exist; 11 bear on `spec/**`.

### 2.2 Agent layer — `src/aief_cad/agents.py`, `.ai/core/agents/`

**Design agents** own requirement *kinds* and reason only within them. Each returns a
`DesignContribution` bounded by a declared write scope over the solution, so an agent reaching
outside its domain is **rejected at merge**, not merged and audited later. Runs record which
agents participated — e.g. `model-setup`, `mechanical.design-engineer`,
`mechanical.simulation-engineer`, `mechanical.manufacturing-engineer`.

Above them sit **12 governance role contracts** — 5 universal (`chief-systems-engineer`,
`project-manager`, `qa-engineer`, `repository-engineer`, `documentation-engineer`), 4
`mechanical`, 3 `software` — each declaring responsibilities, permitted and forbidden actions,
escalation rules and duty conflicts. The load-bearing one is **LAW-05: no role verifies its own
output.**

### 2.3 Design solution — `src/aief_cad/solution.py`

The controlled handoff between reasoning and execution. It states **what should be built**. It
does not state how Fusion will build it, and it does not state what Fusion did build. Its own
docstring gives the reason: *"a layer that lets them blur will eventually report the intent as
the outcome."*

A solution carries driving parameters, features, datums, declared interfaces and the
**acceptance conditions** each requirement demands.

### 2.4 Parameter system — `src/aief_params`, `src/aief_cad/expr.py`

105 driving parameters are derived from the specification's §3 tables and checked by
`python -m aief_params check`. A parameter may be a literal or a derivation over other
parameters; `expr.py` resolves the dependency graph so verification knows the value a derivation
*should* produce.

Expressions evaluate over a **whitelisted AST, never `eval`** — a requirement package is data,
and LAW-13 forbids treating repository content as instruction.

The constraint verifier then checks something subtler than the value: that a **declared
derivation reached Fusion as an expression, not as its current number**. A literal that happens
to be right today silently stops tracking the parameter it came from.

### 2.5 Operation vocabulary — `src/aief_cad/ops.py`

An operation is bounded, validated and single-purpose. The vocabulary **names no component and
encodes no engineering judgement**:

```
ping · new_document · rename_component · set_parameters · create_sketch
sketch_circle · sketch_construction · sketch_path · sketch_profile
radial_plane · offset_plane · extrude · combine · fix_sketch
assign_material · observe
```

That is the **16-operation geometric core** in the add-in shell. An extension module
(`bridge_ops_ext.py`) supplies a 19-entry table that overrides three of them and adds sixteen
more — document lifecycle (`save_document`, `save_as_new_lineage`, `discard_document`,
`revert_document`), assembly (`insert_occurrence`, `transform_occurrence`, `delete_occurrence`,
`update_references`, `observe_assembly`), export and data-file management — **32 distinct
operations in total**.

The rule stated in the module: anything the vocabulary cannot express is *a gap to be closed
here*, not worked around by widening an argument to carry a special case.

Geometry that needs derivation gets a derivation module, not a special-cased operation —
`routing.py` routes a milled channel through an annulus around keep-out features as a bifilar
counterflow family, deriving the pass schedule from envelope, keep-outs, port azimuths, width,
rib and minimum bend.

### 2.6 CAD bridge — `src/aief_cad/bridge/`, `fusion_addin/AIEF_CAD_Bridge/`

**Fusion 360 has no external automation API.** No Design Automation engine; the Fusion Data API
is read-only metadata. The only supported way to drive the modeller is code inside Fusion's own
process, and the only supported way to move work onto the thread that owns the document is a
registered custom event.

So the bridge is:

```
orchestrator                                   Fusion 360
------------                                   ----------
write cad/bridge/queue/NNNN.cmd.json  ──────▶  add-in background thread polls
                                                        │
                                               fireCustomEvent(payload)
                                                        │
                                               handler on the document thread
                                                        │
read  cad/bridge/obs/NNNN.obs.json    ◀────────  writes what it OBSERVED
```

The queue is **transport, not record**: `cad/bridge/queue|obs|state/` are gitignored, and every
command and observation is copied verbatim into `cad/runs/<run>/run.json`, which **is tracked** —
including the failures.

### 2.7 Observation — `src/aief_cad/observe.py`

A deliberately separate type from `DesignSolution`. Its rule:

> **Absence is represented as absence.** A body Fusion did not report is `None`, not an empty
> body with zero volume.

That is why a run record can say `observed None` with the detail *"not present in the observed
model. A check that cannot be evaluated has not passed."* A zero standing in for a missing
measurement is how an unbuilt feature passes a numeric check.

### 2.8 Verification — `src/aief_cad/verify/`

**Three verifiers, one verdict.** Each reads only the `ObservedModel` and the `DesignSolution`.

| Verifier | Owns | Intrinsic checks it adds |
|---|---|---|
| `geometry.py` | `geometry`, `mass` acceptance | body present; extents match the declared extrude distance — so a solution with no acceptance conditions is still not vacuously verified |
| `interface.py` | `interface` acceptance | named construction planes exist at declared offsets; locating sketches later features derive from. An interface not built in this bounded run is reported **`deferred`**, not passed |
| `constraint.py` | `constraint`, `parameter` acceptance | every parameter exists and equals its resolved expression; a declared derivation is still a derivation; sketches are fully constrained |

Full detail, including system- and release-level verification: [`VERIFICATION.md`](VERIFICATION.md).

### 2.9 Failure classification and recovery — `src/aief_cad/loop.py`

```
DESIGN -> EXECUTE -> OBSERVE -> VERIFY -> PASS? -> NEXT
              ^                            |
              +--------- REDESIGN / REPAIR (bounded)
```

A **diagnosis names five things**, "because a failure that names fewer cannot be acted on": the
failed requirement, the observed evidence, the responsible design area, the likely cause, and
the proposed correction. `_classify` then decides the **owning layer** — whether this is a
re-dispatch or an engineering decision:

| Observed subject | Classified as | Repairable |
|---|---|---|
| `parameter:*` absent or wrong | parameters not applied, or applied to a different document | yes — re-dispatch `set_parameters` |
| a declared derivation arrived as a literal | it no longer tracks its source | yes |
| `plane:*` absent or wrong offset | datum missing | yes — re-dispatch `offset_plane` |
| `sketch:*` absent / not fully constrained | a later feature located against it can move | yes |
| `body*` absent or wrong extent | profile/extrude did not produce the declared solid | yes |
| `document.units` wrong | rescales every dimension; cannot be corrected without reinterpreting geometry | **no — escalate** |
| anything unclassified | *"an unclassified failure is not repaired by guessing"* | **no — escalate** |

Two guarantees:

- **No blind retry.** A repair must change the dispatched sequence. The repair sequence's digest
  is compared with the failed attempt's, and an identical sequence is refused with `NO-PROGRESS`.
- **No infinite repair.** Attempts are capped. On exhaustion the loop stops and reports the
  surviving findings — *"it does not degrade into a pass."*

Worked examples with real run records: [`FAILURE_RECOVERY.md`](FAILURE_RECOVERY.md).

### 2.10 Document lifecycle — `cad/DOCUMENT_LIFECYCLE.md`

An earlier architecture defect: `rename_component` had to `saveAs` because Fusion refuses to
rename an unsaved root component — so **persistence preceded geometry**, and failed runs left
saved blank documents behind. The repair:

| Class | Persistence |
|---|---|
| **AUTHORITATIVE** | saved and versioned — first-save happens **only** in `save_document`, dispatched **only on verified PASS** |
| **TEMPORARY / TEST** | never saved — identity bound as a design attribute (`aief:intended_name`), discarded by recovery |
| **FAILED ATTEMPT** | never saved, or reverted if it dirtied a saved baseline |

Enforced by `tests/test_document_lifecycle.py::test_only_the_verified_save_path_may_first_save`.
`discard_document` **refuses a saved document by contract**, so a failure path can never destroy
an authoritative design. Quarantine-by-rename is explicitly *not* cleanup.

### 2.11 Assembly — `src/aief_cad/assembly.py`

An assembly package declares occurrences — which saved design, at which transform, with which
expected placement band — and **every value carries provenance to a governing source**.
Verification reads the observed occurrence list back from Fusion: 19 occurrences, each placed,
grounded, with source design and version, observed bounding box and mass.

### 2.12 Provenance — `src/aief_cad/digest.py`, `.ai/project/ledger/`

Every emitted artifact is identified by the SHA-256 of a **canonical byte form** (UTF-8, sorted
keys, no insignificant whitespace) so a run can be replayed and compared without trusting any
claim written inside it. This is the LAW-10 construction — approval bound to a content hash —
applied to commands, observations and verdicts.

Above it: a **hash-chained ledger** (`SEG-0000/L-000000n`, each linking `prev_hash`), the
31-member freeze registry, the 61-entry deliverable register, and per-dimension drawing
provenance sidecars naming the parameter or specification clause behind every number on every
sheet.

### 2.13 Standing checks — `src/`

Eight modules that **compute** the properties the documents claim, rather than restating them:

| Command | Property | Exit at `v0.11.0` |
|---|---|---|
| `python -m aief_gate` | gate `LC-M04-EXIT` criteria C1–C7, read from the ECR records directly | 0 |
| `python -m aief_clearance` | `spec/00` §3.2 feature clearance, pair by pair | 0 |
| `python -m aief_params check` | the 105-parameter master against the package | 0 |
| `python -m aief_approval verify` | approval-chain integrity under LAW-10 | 0 |
| `python -m aief_deliverables` | 61 deliverables against their register, **both directions** | 0 |
| `python -m aief_register` | no state register asserts a value another artifact governs | 0 |
| `python -m aief_stage6` | the framework's own release build; boot step B2a | 0 |
| `python -m aief_analysis` | `SR-07`/`AP-08` loads and the `SR-02/03/04` insulation trace | **1 — 4 of 5 checks FAIL** |
| `python -m aief_exec check` | exec-layer token budgets | **1 — 7 of 10 PASS** |

The two non-zero exits are the point, not an oversight. `aief_analysis` files the `SR-03`/`SR-04`
trace and the trace does not close — a check reporting PASS on `ECR-D-016` would itself be the
defect. `aief_exec check` reports three open exec-layer conditions of its own. Both exit non-zero
because something is genuinely open, and both are documented as such rather than muted.

A third, `aief_stage6`, exits 0 here but **halts from a clean clone**: it needs third-party
tokenizer artifacts that are not tracked, and `budget_measurement_record` rules that their
absence *blocks* rather than estimates. It refuses to guess.

> **Four defect classes went unnoticed for many sessions, and every one was a declared property
> with no standing check.** That is the lesson the repository is organised around.

### 2.14 Release integrity

`framework/` is compiled through a **six-stage compiler**; Stage 6 emits `.ai/core/MANIFEST.lock`
and the `BINDING.core_digest_pin`. Boot step **B2a** recomputes DC-1 over the 75 covered files,
recomputes DC-4, and compares both to the lock and the pin — 75/75, recomputed independently
without importing the code being audited. `git` is the transport; the digests are the record.

---

## 3 · What is deliberately *not* automated

- **The Fusion add-in "Run" toggle.** Fusion's per-user add-in Run state is a QML control opaque
  to UI Automation; synthetic pointer events do not land, and the desktop is in human use, so
  injecting them is unsafe. This is the single genuinely human-gated step, and it is recorded as
  such in `cad/BRIDGE_RESUME.md` rather than papered over.
- **The parametric `.f3d`.** `SEDEP-PMP-002` §3.1 places the parametric source of record in
  Fusion cloud versioning; git holds the neutral record (STEP) and the drawings.
- **Engineering decisions.** An unclassified failure escalates. An ambiguity becomes an ECR
  (LAW-12), never an assumption.
- **Physical qualification.** See [`VERIFICATION.md` §6](VERIFICATION.md).

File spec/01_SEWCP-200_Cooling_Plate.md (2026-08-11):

# SEWCP-ENG-002 — Cooling Plate

**Part Number:** SEWCP-200 · **Volume:** 01 of 09 · **Revision:** A
**Parent:** SEWCP-ENG-001 Architecture & ICD · **Stack position:** 2 (above Support Ring, below Heater Plate)

---

## 1. Engineering Purpose

The Cooling Plate is the **thermal ground of the platform and the RF bias electrode of the chuck**. It performs four jobs simultaneously, and every feature on it traces to one of them:

1. **Heat sink.** It removes plasma-deposited heat and heater trim power from the stack via a closed-loop liquid circuit, establishing the baseline temperature from which the heater works upward.
2. **Structural backbone.** It is the stiffest member of the thermal stack and carries the Heater Plate and ESC. Its flatness propagates directly to the wafer plane.
3. **RF bias electrode.** In Configuration A it is the powered 13.56 MHz electrode, capacitively coupled to the plasma through the ESC dielectric.
4. **Utility manifold.** All services to the ESC — helium, HV, lift pins, temperature probes — pass through it.

It is deliberately *not* in intimate thermal contact with the Heater Plate. The thermal choke between them is what makes closed-loop wafer temperature control possible (SEWCP-ENG-001 §4.3).

## 2. Functional Requirements

| ID | Requirement | Value | Verification |
|---|---|---|---|
| CP-01 | Heat removal capacity | ≥ 3000 W | Calorimetric test |
| CP-02 | Coolant flow rate at rated ΔP | 4.0 L/min at ΔP < 1.5 bar | Flow bench |
| CP-03 | Coolant temperature range | −20 °C to +80 °C | — |
| CP-04 | Coolant fluid | 50/50 water-glycol (baseline); Galden HT-135 (alt) | — |
| CP-05 | Proof pressure | 6.0 bar, 30 min, no permanent deformation | Hydrostatic |
| CP-06 | Burst pressure | ≥ 15 bar | Sample test, 1 per lot |
| CP-07 | Coolant circuit leak rate | < 1×10⁻⁹ mbar·L/s He | Mass spec |
| CP-08 | Top face flatness | ≤ 0.015 mm TIR over Ø300 | CMM |
| CP-09 | Top-to-bottom parallelism | ≤ 0.015 mm TIR | CMM |
| CP-10 | Overall thickness | 20.000 ± 0.030 mm | Micrometer, 8 points |
| CP-11 | Radial temperature uniformity of top face | ≤ 1.5 °C across Ø280 at 3 kW | Thermal map |
| CP-12 | Electrical isolation from Base Plate (installed) | ≥ 1 GΩ at 1000 VDC | Megohmmeter |
| CP-13 | RF strap contact resistance at land | ≤ 0.5 mΩ | 4-wire micro-ohmmeter |
| CP-14 | Outgassing | < 1×10⁻⁷ Torr·L/s·cm² at 150 °C | RGA |
| CP-15 | Mass | ≤ 4.2 kg | Scale |

### 2.1 Coolant Circuit Sizing (design basis)

| Parameter | Value | Derivation |
|---|---|---|
| Channel cross-section | 10.0 mm W × 6.0 mm D | Depth set by the Z stack: `CP-D07` 8.00 + `CP-D06` + `CP-D08` 6.00 = `CP-D02` 20.000 (ECR-D-002) |
| Flow area | 60 mm² = 6.0×10⁻⁵ m² | — |
| Volumetric flow | 4.0 L/min = 6.67×10⁻⁵ m³/s | CP-02 |
| Mean velocity | **1.11 m/s** | Q/A |
| Hydraulic diameter | 7.50 mm | 4A/P |
| Reynolds number | **≈ 8,300** | ρvD/µ — **turbulent**, as required for high h. Higher than the 8 mm form: velocity gains more than hydraulic diameter loses |
| Convective coefficient | ≈ 6,500 W/m²·K | Dittus-Boelter, h ∝ Re⁰·⁸/D |
| Developed path length | ≈ 2.2 m | Serpentine layout |
| Wetted area | ≈ 0.080 m² | Path × perimeter (perimeter 36 → 32 mm) |
| Coolant ΔT at 3 kW | **10.8 K** | Q / (ṁ·c_p), ṁ = 0.0667 kg/s |

> **`ECR-D-002`: `CP-02`'s pressure drop is NOT re-derived here and must be re-verified.**
> Reducing the depth from 8.00 to 6.00 mm raises velocity and lowers hydraulic diameter,
> so ΔP rises materially. `CP-02` declares *4.0 L/min at ΔP < 1.5 bar* and is verified on a
> **flow bench** — this specification states no ΔP value and none is invented here. The
> thermal direction is favourable and is stated above: `h` rises ≈ 30 % while wetted area
> falls ≈ 11 %, so `hA` improves ≈ 16 % and `CP-01`/`CP-11` gain margin. The hydraulic
> direction is adverse and is open. **`CP-02` shall be verified before build release.**

Turbulence is a **requirement, not an outcome.** If flow drops below ≈ 2 L/min the channel goes transitional, h collapses, and the top-face uniformity requirement (CP-11) is lost. A minimum-flow interlock is required at the system level.

## 3. Mechanical Interfaces

| IF | Interface | Type | Detail |
|---|---|---|---|
| CP-IF-1 | To Chuck Support Ring (SEWCP-400) | Kinematic, load-bearing | 3× SEWCP-700 **integral shouldered locator screws** in the bottom face at Ø306 BC, 60°/180°/300° — Ø10.0 H7 × 3.00 counterbore receiving the Ø10.000 **h6** flange (close clearance, 0 to 0.024), retained by the locator's own `AP-D13` M4 spigot into `CP-D09a`; driven at the `AP-D14` 3.0 mm hex socket. The Ø6.000 h6 boss protrudes 2.50 mm and engages radial slots in the Ring's top flange (ECR-D-001 disposition A; ECR-D-009) |
| CP-IF-2 | To Chuck Support Ring — fastening | Fastened, RF-side circuit | 8× **M6 × 1.0 tapped holes**, 12 mm deep, in the bottom face at Ø302 BC, 22.5°+n·45°; upper-circuit bolts enter from beneath the Ring's top flange (DR-9 — these bolts never reach the Base Plate) |
| CP-IF-3 | To Heater Plate (SEWCP-300) | Thermal choke + fastened | 16× M5 **radially slotted** clearance holes, 5.5 W × 7.0 L (12 at Ø270 BC, 4 at Ø90 BC), each with a **radially slotted counterbore `CP-D26` 11.0 W × 12.5 L × 2.5 deep** in the bottom face, **anodize-masked**, seating the Belleville and bolt head; **M5 × 25 SHCS** from below into the `HP-D12` inserts (**not M5 × 30** — ECR-D-004); 16× Ti washer seats on the top face |
| CP-IF-4 | To Heater Plate | Kinematic | 3× SEWCP-700 **integral shouldered locator screws** in the top face at Ø260 BC, **75°/195°/315°** (re-clocked off the outer choke rays — ECR-D-010) — Ø10.0 H7 × 3.00 counterbore receiving the Ø10.000 **h6** flange, retained by the `AP-D13` spigot into `CP-D10a`. The Ø6.000 h6 boss protrudes 2.50 mm and engages radial slots in the Heater Plate (ECR-D-001 disposition A; ECR-D-009; ECR-D-010) |
| CP-IF-5 | To Vacuum Port (SEWCP-800) | Sealed, piloted bore | Central Ø10.0 H8 bore (receives the port-body pilot spigot); flat lapped sealing face on the bottom face, **masked from anodize**, Ø18–Ø32 annulus; 4× M4 × 10 deep tapped holes at Ø38 BC. **The O-ring groove is in the 316L port flange, not in this plate** (see Volume 07 §12) |
| CP-IF-6 | To Lift Pins (SEWCP-600) | **Loose lateral support** | 3× Ø8.0 H8 bores at Ø200 BC, counterbored Ø12 × 6 deep from below for the SEWCP-601 bushing (bushing bore Ø5.60 — deliberately loose; the pin is guided by the ESC bore, see Volume 05 §12) |
| CP-IF-7 | To ESC HV feed | Insulated bore | 2× Ø8.0 bores at Ø60 BC, alumina-tube-lined, 0°/180° |
| CP-IF-8 | To RF Bracket (SEWCP-900) | Bolted electrical land | Machined flat land, **60 mm circumferential × 18 mm radial, mean radius 137 mm (Ø274 BC), centred at 105°**, on the bottom face; **anodize-masked, Alodine 1200 only**; 2× M6 × 12 deep tapped at r = 137, 98.7° and 111.3°; **plus 2× M6 × 12 deep bracket taps at r = 150, 88° and 122°** (RF-IF-3 hanger mounting — ECR-Q-012 DEC-02 as corrected by its addendum: the r = 137 window is occupied by the 30°-pitch choke slots; r = 150 at ±17° clears the choke, ring-bolt, locator, land, RTD and channel patterns) |
| CP-IF-9 | To Temp Sensor Retainers (SEWCP-1000) | Blind probe ports + retainer mounts | 3× Ø1.7 H8 × 12 deep blind holes entering the bottom face at **r = 40 @ 75°, r = 100 @ 165°, r = 140 @ 225°** (clocked clear of the RF land at 105°); **each cross-vented per DR-6**; plus 2× M4 × 8 deep tapped holes flanking each port at ±9 mm |
| CP-IF-10 | To coolant system | Fluid | 2× radial ports at 255° (inlet) / 285° (outlet). Ø10.0 H9 bore (`CP-D22`) on a centreline **11.00 mm above Datum A** (`CP-D23`), running from the OD to the channel at r = 125.0; the channel is locally deepened to 10.00 (`CP-D25`) so bore and channel are **coaxial** and the section matches. Ø14.0 H8 × 4.0 weld-prep counterbore at the OD (`CP-D24`) receives the 6061 end of a **SEWCP-201 bimetallic transition joint**, orbital-GTAW full penetration; the joint's 316L end carries the 1/2 in. VCR male gland (ECR-D-003) |

### 3.1 Coolant Channel Keep-Out Zones

The channel is confined to the **Ø60 to Ø250 annulus** (outer limit pulled in from Ø260 to leave solid material under the RF land) and shall maintain the following minimum wall thicknesses from every feature:

| Feature | Keep-out radius from feature axis | Min. wall to channel |
|---|---|---|
| Central He bore (Ø10) | 15 mm | 5.0 mm |
| Lift pin bores (Ø8, at Ø200 BC) | 12 mm | 4.0 mm |
| HV feed bores (Ø8, at Ø60 BC) | 12 mm | 4.0 mm |
| Choke fastener holes (M5, Ø90 & Ø270 BC) | 8 mm | 3.5 mm |
| Support Ring tapped holes (M6, Ø302 BC) | 9 mm | 3.5 mm |
| RTD blind ports | 6 mm | 3.0 mm |
| **RF land envelope** (r = 128 to 146, 93°–117°) | — | **No channel permitted; solid material required for M6 threads** |
| Plate OD and any external surface | — | 5.0 mm |

> **Port exception — bounded, and declared rather than discovered (ECR-D-003).** At the two
> coolant ports only, the channel is deepened to `CP-D25` 10.00 mm so the Ø10.0 stub bore is
> coaxial with it, and it reaches the plate OD through `CP-D22`. Over those two pockets the
> channel-to-top-face wall is **4.00 mm**, not `CP-D07`'s 8.00, and the *"Plate OD … 5.0 mm"*
> row above does not apply. Both departures are deliberate, are confined to the two pockets,
> and every other row of the table applies unchanged. Structural check at `CP-05` 6 bar proof:
> a 4.00 mm ligament spanning the 10 mm bore carries M = pL²/8 = 7.5 N·mm/mm, so
> σ = 6M/t² = 45 / 16 = **2.8 MPa** against 276 MPa yield — a margin of order 100×.
>
> **Kinematic locators (ECR-D-007 requested action 1).** The row below is added to the table
> above: *Kinematic locator counterbore Ø10.000 and its coaxial M4 thread — keep-out radius
> **8.5 mm** from the feature axis (5.0 counterbore radius + 3.5 wall), minimum wall to channel
> **3.5 mm**.* Constructed on the same basis the table already uses for the M5 choke and M6 ring
> holes. At the Ø260 BC stations this pulls the channel outer limit to **r ≤ 121.5**, which
> leaves the M4 tap drill (inner edge r = 128.35) **6.85 mm** of wall — so ECR-D-007 requested
> action 2 is answered by satisfying this row, not by granting an exception. The Ø306 BC
> stations lie at r = 153, outside the Ø60–Ø250 annulus, and are governed by the plate OD:
> the Ø10.000 counterbore leaves **2.00 mm** of annular wall (1.93 mm worst case).
>
> **This keep-out table is a direct consequence of DR-2** (no fasteners through the wafer-facing surface). Because all 24 fasteners come from below, the coolant circuit must weave around them. CAD shall route the serpentine to satisfy the table **before** optimizing for path length.

## 4. Mating Components

| Mates To | Part No. | Interface | Nature of Constraint |
|---|---|---|---|
| Chuck Support Ring | SEWCP-400 | CP-IF-1, CP-IF-2 | Supported on; kinematically centered; electrically isolated from ground by it |
| Heater Plate | SEWCP-300 | CP-IF-3, CP-IF-4 | Carries it through the thermal choke; kinematically centered |
| Vacuum Port Assembly | SEWCP-800 | CP-IF-5 | Sealed bolted flange, bottom face |
| Lift Pins / Bushings | SEWCP-600 / -601 | CP-IF-6 | Guides pin travel |
| Electrostatic Chuck | SEWCP-500 | Indirect (via Heater Plate) | No direct contact |
| RF Feedthrough Bracket | SEWCP-900 | CP-IF-8 | Receives RF power at the bolted land |
| Temperature Sensor Bracket | SEWCP-1000 | CP-IF-9 | Receives spring-loaded RTD probes |
| Base Plate | SEWCP-100 | Via SEWCP-400 only | **No direct contact — isolation depends on it** |
| Alignment Pins | SEWCP-700 | CP-IF-1, CP-IF-4 | Hosts 6 screw-retained locators (3 down, 3 up) |
| Coolant Transition Joint | SEWCP-201 | CP-IF-10 | 2 off. Explosion-bonded 6061/316L; welded to the plate on the 6061 side, carries the VCR gland on the 316L side |

## 5. Critical Dimensions

| Ref | Dimension | Nominal | Tolerance | Criticality |
|---|---|---|---|---|
| CP-D01 | Outside diameter | Ø320.0 | ±0.10 | Low |
| CP-D02 | **Overall thickness** | **20.000** | **±0.030** | **Critical — Z stack** |
| CP-D03 | Top face flatness | — | 0.015 TIR | **Critical — wafer plane** |
| CP-D04 | Top-to-bottom parallelism | — | 0.015 TIR | **Critical — wafer plane** |
| CP-D05 | Coolant channel width | 10.00 | +0.20 / −0 | Medium |
| CP-D06 | Coolant channel depth | 6.00 | +0.20 / −0 | **Medium — set by the Z stack, ECR-D-002** |
| CP-D07 | Channel-to-top-face wall | 8.00 | ±0.20 | Medium — thermal |
| CP-D08 | FSW lid thickness | 6.00 | ±0.10 | Medium |
| CP-D09 | Kinematic locator counterbore (bottom), Ø306 BC, 3.00 deep | **Ø10.000** | H7 | **Critical — centering.** Reduced from Ø12.000 by ECR-D-007 action 3: the Ø12 form left **1.00 mm** of annular wall to the plate OD (0.95 mm at minimum OD); Ø10.000 leaves **2.00 mm** (1.93 worst case) |
| CP-D09a | Locator retention tapped hole (bottom), coaxial with `CP-D09` | M4 × 0.7. Ø3.30 drilled, **7.80 max to the drill point** below the counterbore floor; **5.00 min full thread**, bottoming tap | — | **High — retention.** Crosses the FSW lid/body plane at z = 6.00: a circumferential weld pass shall lie at or outboard of this bolt circle (ECR-D-007 action 5) |
| CP-D10 | Kinematic locator counterbore (top), Ø260 BC **@ 75°/195°/315°**, 3.00 deep | **Ø10.000** | H7 | **Critical — centering** (re-clocked, ECR-D-010; Ø12.000 → Ø10.000, ECR-D-007 action 3 — which also moves this counterbore's inner edge from r = 124.0 to **r = 125.0**, closing the §3.2 annulus overlap) |
| CP-D10a | Locator retention tapped hole (top), coaxial with `CP-D10` | M4 × 0.7. Ø3.30 drilled, **7.80 max to the drill point** below the counterbore floor; **5.00 min full thread**, bottoming tap | — | **High — retention.** 5.00 mm stops exactly at `CP-D07`'s 8.00 mm wall; radial separation is the §3.1 locator row (ECR-D-007 action 5) |
| CP-D11 | Kinematic locator counterbore position | Ø306 / Ø260 | ⌖ Ø0.020 M @ B,C | **Critical** |
| CP-D12 | Lift pin bore | Ø8.000 | H8 | High — pin alignment |
| CP-D13 | Lift pin bore position | Ø200 BC | ⌖ Ø0.050 M @ A,B,C | High |
| CP-D14 | Lift pin bore perpendicularity to Datum A | — | 0.030 over 20 mm | **Critical — pin bind** |
| CP-D15 | Central He bore | Ø10.000 | H8 | Medium |
| CP-D16 | Vacuum port sealing face (flat, masked, Ø18–Ø32) | Flatness 0.010, Ra 0.8–1.6 | — | **Critical — seal** |
| CP-D17 | Choke washer seat pads (16×) | Ø22 flat, coplanar | 0.010 TIR set | **Critical — R_choke** |
| CP-D18 | RF land flatness | 60 × 18 land, Ø274 BC @ 105° | 0.020 TIR | **Critical — contact R** |
| CP-D19 | RTD blind bore (3×, r = 40/100/140 @ 75°/165°/225°) | Ø1.700 | H8, depth 12 ±0.2 | High — response |
| CP-D20 | M6 tapped holes (Ring upper circuit), Ø302 BC | M6 × 1.0 × 12 deep | ⌖ Ø0.30 Ⓜ | Low |
| CP-D21 | M5 tapped depth (into Heater Plate side) | — | `HP-D12`, 6.50 blind | — |
| CP-D22 | Coolant stub bore (2×), radial at 255° / 285° | Ø10.0 | H9 | Medium — flow |
| CP-D23 | Coolant stub bore centreline above Datum A | 11.00 | ±0.10 | **High — channel breakthrough** |
| CP-D24 | Stub weld-prep counterbore at the OD (2×), coaxial with `CP-D22` | Ø14.0 × 4.0 deep | H8 | High — weld fit-up |
| CP-D25 | Channel local depth at the two ports, ramped to `CP-D06` over 15 mm | 10.00 | +0.20 / −0 | Medium — set by `CP-D22` (ECR-D-003) |
| CP-D26 | Choke fastener counterbore (16×), radially slotted, coaxial with `CP-IF-3` | 11.0 W × 12.5 L × 2.5 deep | +0.20 / −0 | High — head seat, slip interface |

**Mass estimate:** Ø320 × 20 mm 6061 solid = 4.34 kg; less channel volume (≈ 0.13 L) and bores ≈ **4.0 kg**. Meets CP-15 (≤ 4.2 kg), with the margin narrowed from ≈ 0.3 to ≈ 0.2 kg by the ECR-D-002 depth reduction.

## 6. Manufacturing Method

**Two-piece construction, friction-stir-welded.**

| Step | Operation | Notes |
|---|---|---|
| 1 | Procure 6061-T651 plate, Ø330 × 30 rough | Certified, ultrasonically inspected for porosity |
| 2 | Rough machine body OD, faces; stress-relieve | **Mandatory** — 6061 plate carries residual stress that will bow the part after channel machining |
| 3 | CNC mill the serpentine channel into the **bottom** face | 10 W × 6 D (`CP-D05` × `CP-D06`), R5 minimum bend radius, all corners filleted R3 minimum. Deepen to 10 D at the two port pockets per `CP-D25`, ramped back to 6 D over 15 mm |
| 4 | Machine the FSW lid, 6.00 mm, matching profile | Same 6061-T651 lot |
| 5 | **Friction stir weld** the lid to the body | Circumferential + internal rib passes; no filler, no flux, no elastomer in the pressure boundary. **Internal-rib passes on the 5.0 design rib (ECR-Q-011 disposition, DEC-03): tapered probe, tip Ø ≤ 4.0 — the shoulder rides the continuous lid; seam tracking ≤ ±0.5; penetration 6.5–7.0 (0.5–1.0 into the rib). Supplier capability confirmed at RFQ** |
| 6 | NDT the weld — dye penetrant + radiography | Weld defects here are a coolant-into-vacuum event (FMEA #6) |
| 7 | Hydrostatic proof, 6 bar / 30 min | Before any finish machining |
| 8 | Semi-finish all faces; second stress relief | |
| 9 | Finish machine: bores, counterbores, choke pads, RF land, O-ring groove, tapped holes | Single setup where possible to hold CP-D11 |
| 10 | Bore `CP-D22` / `CP-D24`; orbital-GTAW the 2× SEWCP-201 transition joints into the weld-prep counterbores | Full-penetration, internally smooth. **6061-to-6061 fusion only** — the Al/316L interface is the explosion bond inside SEWCP-201 and is never a fusion weld (ECR-D-003) |
| 11 | Helium leak test, < 1×10⁻⁹ mbar·L/s | Mass spectrometer, He bagged |
| 12 | Install 6× alignment locators (SEWCP-700) | 3 bottom, 3 top. **Integral shouldered locator screws** — no separate fastener. Torque **1.2 N·m** at the `AP-D14` 3.0 mm hex socket, anti-galling dry film on the spigot and flange face (ECR-D-009) |
| 13 | **Mask** channel interior, choke pads, RF land, sealing faces, locator counterbores and their M4 threads, and the 16× `CP-D26` counterbore floors; hard anodize | See §8. The `CP-D26` floors are masked because that joint **slips ≈ 0.4 mm every thermal cycle** under ≈ 3.9 kN of preload, and hard anodize is friable — bearing a Belleville on it generates wear debris in vacuum (ECR-D-004) |
| 14 | Strip masks; final lap the top face | To CP-D03 / CP-D04 |
| 15 | Clean: ultrasonic → DI rinse → IPA → vacuum bake 120 °C / 4 h | Per SEWCP-ENG-001 §10 C1 |
| 16 | Final inspection and CMM report | Full dimensional per §5 |

**Alternative constructions considered:**

| Method | Verdict |
|---|---|
| **Friction stir welding (selected)** | Full-strength joint, no filler, vacuum-clean, proven in semiconductor chuck manufacture |
| Vacuum brazing (Al-Si filler) | Viable alternate; risk of filler flow into the channel and of T6 temper loss requiring re-solutionizing |
| Gun-drilled cross-bores with plugs | Cheapest, but plugs are leak paths and the routing cannot avoid the fastener keep-outs |
| O-ring-sealed bolted lid | **Rejected** — an elastomer in the coolant pressure boundary facing vacuum is an unacceptable single-point contamination risk |

**Stress relief is called out twice and is not optional.** A 20 mm aluminum plate with 60% of its lower face milled into a channel will move. Machining flat and then discovering 80 µm of bow at final inspection is the classic way to scrap this part.

## 7. Material

**6061-T6 / T651 aluminum alloy.**

| Property | Value | Relevance |
|---|---|---|
| Thermal conductivity | 167 W/m·K | Spreads heat; keeps plate-internal ΔT < 1 K |
| Density | 2,700 kg/m³ | Mass budget |
| CTE | 23.6 ppm/K | Drives the kinematic constraint scheme |
| Specific heat | 896 J/kg·K | Thermal time constant |
| Yield strength (T6) | 276 MPa | Pressure boundary, bolt preload |
| Elastic modulus | 68.9 GPa | Stiffness / deflection |
| Vacuum compatibility | Excellent when anodized and cleaned | — |

**Rationale for 6061-T6 over alternatives:**

| Candidate | k (W/m·K) | Why not selected |
|---|---|---|
| **6061-T6** | 167 | **Selected** — best k/machinability/cost/weldability combination; FSW-proven |
| 1100 / 6063 | 222 / 201 | Higher k, but too soft for threads and bolt preload |
| Cu C10100 | 391 | Excellent k, but 3.3× the mass, poor for RF-hot floating body, galvanic and contamination issues |
| 316L SS | 16 | 10× worse k — would destroy CP-11 uniformity |
| AlSiC-9 MMC | ~190 | Excellent, but unnecessary here (the CTE-match problem lives at the ESC bond, not this plate) |

## 8. Surface Finish

| Surface | Finish | Reason |
|---|---|---|
| Top face (choke side) | Lapped Ra ≤ 0.4 µm, **bright, NOT anodized**, emissivity ε ≤ 0.15 | Anodize would raise ε to ~0.8 and add ~50 W of radiative coupling across the choke gap, degrading the deliberate thermal break |
| Choke washer seat pads (16×) | Lapped Ra ≤ 0.4 µm, masked from anodize, coplanar 0.010 TIR | Contact conductance drives R_choke; anodize is an insulator and would make R_choke unpredictable |
| RF land (CP-IF-8) | Ra ≤ 0.8 µm, **masked from anodize**, chromate conversion (Alodine 1200) only | Must be electrically conductive; Alodine is conductive, anodize is not |
| Coolant channel interior | As-milled Ra ≤ 3.2 µm, deburred, **masked from anodize** | Anodize flakes into the coolant loop and blocks the heat exchanger |
| O-ring sealing face | Ra 0.8–1.6 µm, no radial scratches | Seal integrity |
| Lift pin bores | Ra ≤ 0.8 µm, honed | Pin travel without stick-slip or galling |
| Bottom face and OD (exposed) | **Type III hard anodize, 50 µm, sealed** | Plasma and handling durability; dielectric protection of the RF-hot body |
| Locator counterbores and M4 retention threads | Ra ≤ 0.8 µm, masked | Flange seating and thread integrity. Locators are installed **after** the anodize tank — see §6 steps 12–13 |

> **The masking drawing is as important as the machining drawing.** Five distinct surfaces on this part must be excluded from anodize for three different reasons — thermal (choke face), electrical (RF land), and contamination (channel interior). A single missed mask converts a controlled thermal choke into an unknown one.

## 9. Tolerances

**GD&T scheme:**

- **Primary datum A** — bottom face (seats on the Support Ring), flatness 0.015.
- **Datum B** — the Ø306 BC kinematic locator counterbore at 60°.
- **Datum C** — the Ø306 BC kinematic locator counterbore at 180° (clocking).

| Control | Feature | Tolerance |
|---|---|---|
| Flatness | Top face | 0.015 |
| Flatness | Bottom face (Datum A) | 0.015 |
| Parallelism | Top face to A | 0.015 |
| Profile | Choke pad set, coplanar | 0.010 |
| Position | Kinematic locator counterbores | ⌖ Ø0.020 Ⓜ A B C |
| Position | Lift pin bores | ⌖ Ø0.050 Ⓜ A B C |
| Perpendicularity | Lift pin bores to A | 0.030 |
| Position | Choke fastener holes and their `CP-D26` counterbores | ⌖ Ø0.200 Ⓜ A B C |
| Position | Coolant stub bores `CP-D22` | ⌖ Ø0.50 Ⓜ A B C |
| Parallelism | Coolant stub bore axis to A | 0.20 over 35 mm |
| Position | Central He bore | ⌖ Ø0.100 Ⓜ A B C |
| Profile | O-ring groove | 0.050 |
| Runout | OD to A | 0.20 |
| Thickness | 20.000 ±0.030 | Measured at 8 points, 45° apart, Ø280 BC |

**Tolerance philosophy:** only three characteristics on this part are tight — plate thickness, top-face flatness/parallelism, and kinematic locator position. Everything else is opened deliberately. Choke fastener holes at ⌖ Ø0.200 and lift pin bores at ⌖ Ø0.050 are loose *by design*, because those features are located functionally (by Belleville-preloaded slip joints and by ESC-side bushings respectively), not by the plate.

## 10. Assembly Sequence

**Sub-assembly (off-tool) — corresponds to SEWCP-ENG-001 §10 steps A1–A2:**

1. Complete manufacture per §6 through step 16.
2. Record as-built thickness at 8 points; enter into the build traveller (feeds the Support Ring lap calculation, DR-3).
3. Install the 6 alignment locators (SEWCP-700): 3 into the bottom face at Ø306 BC (60°/180°/300°), 3 into the top face at Ø260 BC (**75°/195°/315°**). Each locator is a one-piece shouldered screw: enter the flange in its Ø10.0 H7 × 3.00 counterbore by hand — it is a clearance fit — and torque to **1.2 N·m** at the 3.0 mm hex socket. **Verify boss protrusion 2.50 ± 0.05 mm above the seated flange face** — the boss must remain shorter than the 3.00 mm mating slot is deep, or it bottoms and holds the faces apart (SEWCP-700 §5.1).
4. Install lift pin bushings (SEWCP-601) into the bottom counterbores; verify bore Ø5.60 +0.05/−0 after installation.
5. Install alumina liner tubes into the 2 HV feed bores; bond with vacuum-grade epoxy; verify IR > 1 GΩ.
6. Verify VCR stub cleanliness; cap.

**Installation into the stack — corresponds to §10 steps C2–C5:**

7. **Inverted, off-tool:** with the Cooling Plate bottom-face-up on a padded fixture, seat the Support Ring so the 3 bottom locator bosses enter its top-flange radial slots. **Confirm each boss slides freely in its slot** — a bound locator means the slots are mis-clocked, and torquing will crack the ceramic on the first thermal cycle.
8. Install the 8× upper-circuit M6 × 16 bolts from beneath the Ring's top flange into the Cooling Plate tapped holes, with Ø16 washers and Belleville stacks. Torque in 3 passes (30 / 70 / 100%), star pattern, to **6.0 N·m**. Re-confirm free slide.
9. After the assembly has been inverted onto the Base Plate and the lower circuit torqued (Volume 03 §10 Phase 3), measure insulation resistance Cooling Plate → Base Plate: **≥ 1 GΩ at 1000 VDC**. A failure here means a cracked web or a conductive particle bridging it — stop and disassemble.
10. Place the thickness-sorted set of 16 titanium choke washers on their pads.
11. Proceed to Heater Plate installation (Volume 02).

**Disassembly note:** the Cooling Plate cannot be removed without first removing the Heater Plate + ESC sub-assembly, because its retaining bolts are captured beneath. This is accepted; the ESC is the life-limited item and is intended to be replaced as a bonded sub-assembly anyway.

## 11. Failure Modes

| # | Failure Mode | Cause | Effect | S | O | D | RPN | Mitigation |
|---|---|---|---|---|---|---|---|---|
| 1 | Coolant leak into vacuum | FSW defect, weld porosity, stub weld crack | **Catastrophic** chamber contamination, full teardown | 10 | 2 | 3 | **60** | FSW (no elastomer/filler), radiography, 6 bar proof, He leak test, burst sample per lot |
| 2 | Plate bow after machining | Residual stress in plate stock | Fails CP-08/09; wafer plane out of spec | 7 | 6 | 2 | **84** | Two stress-relief cycles (§6 steps 2, 8); final lap after anodize |
| 3 | Flow below turbulent threshold | Pump degradation, partial blockage, wrong fluid viscosity | Re drops < 2300, h collapses, CP-11 uniformity lost, local hot spot | 7 | 4 | 4 | **112** | Minimum-flow interlock at 2.5 L/min; ΔP monitoring; inlet strainer |
| 4 | Anodize flakes into coolant loop | Channel interior not masked | Heat exchanger fouling, progressive capacity loss | 6 | 4 | 6 | **144** | Explicit masking drawing; borescope inspection after anodize |
| 5 | Choke pad anodized in error | Masking error | R_choke unpredictable and high; wafer temperature uncontrollable | 7 | 3 | 5 | **105** | Masking drawing; post-anodize contact-resistance check on all 16 pads |
| 6 | RF land contact resistance rise | Anodize on land, low preload, oxidation, thermal cycling | I²R heating → arc → plate damage | 8 | 3 | 4 | **96** | Alodine only on land, 8 N·m preload, Belleville, 4-wire check in ATP |
| 7 | Lift pin bore galling / pin bind | Bore not honed, misalignment, particle ingress | Wafer handling fault, possible wafer breakage | 7 | 4 | 3 | **84** | Ra ≤ 0.8 honed bore, 0.030 perpendicularity, Vespel bushing |
| 8 | Corrosion / erosion of channel | Glycol degradation, galvanic Al/316L couple in the SEWCP-201 transition joint, cavitation | Wall thinning → leak (→ FM #1) | 8 | 3 | 6 | **144** | Inhibited glycol, annual fluid analysis, R5 min bend radii to limit erosion; the dissimilar couple is confined to the short wetted length of the SEWCP-201 explosion bond rather than distributed along an Al-to-SS fusion weld, which is not metallurgically possible in any case (ECR-D-003) |
| 9 | Freeze burst | Chiller fault below fluid freeze point | Channel rupture | 9 | 2 | 3 | **54** | 50/50 glycol (−37 °C protection), low-temperature interlock |
| 10 | Virtual leak from RTD blind bores | Un-vented blind holes | Fails pump-down qualification | 5 | 5 | 6 | **150** | DR-6: cross-vent every blind bore |
| 11 | Thread stripping in M5/M6 tapped holes | Over-torque into aluminum | Loss of preload, joint separation | 6 | 3 | 3 | **54** | Torque schedule, min 2×D thread engagement, consider stainless inserts on rework |

**Highest-RPN items are 10 (virtual leaks), 4 and 8 (both coolant-loop contamination/corrosion), and 3 (loss of turbulence).** Note that the *catastrophic* failure (coolant into vacuum, S=10) has a modest RPN only because the manufacturing controls make occurrence low — which is exactly why FSW plus radiography plus proof plus leak test are all specified rather than any one of them.

## 12. Design Rationale

**Why a liquid-cooled plate rather than conduction to the Base Plate?**
Because the Base Plate is chamber-coupled and uncontrolled (FBA-7). Any architecture that relies on it for heat rejection makes wafer temperature a function of chamber wall temperature — which drifts with process history, chamber cleans, and idle time. A closed-loop liquid circuit makes the chuck's thermal boundary condition an *input* rather than a disturbance.

**Why is the coolant channel in the bottom face with an FSW lid, rather than the top face?**
Two reasons. First, the top face must be lapped flat to 15 µm and hold the choke pads coplanar to 10 µm — putting a weld seam there would make that impossible. Second, keeping the weld on the low-stress side, away from the wafer plane, means weld distortion is corrected by the final lap rather than propagating to the wafer.

**Why 10 × 6 mm channel at 4 L/min?**
The channel is sized backwards from the Reynolds number, not from pressure drop. At 4 L/min the velocity is 1.11 m/s and Re ≈ 8,300 — comfortably turbulent with margin for viscosity increase at low temperature. Sizing for a lower ΔP with a bigger channel would have dropped the flow laminar and cost far more in uniformity than it saved in pump power.

**Why is the plate the RF electrode instead of adding a dedicated one?**
Adding a separate electrode adds a joint, and every RF joint is a contact-resistance and arcing site. The Cooling Plate is already a large, low-impedance aluminum mass directly beneath the ESC dielectric — it *is* the natural electrode. The cost of this decision is that every service entering it needs an RF break (SEWCP-ENG-001 §6.5), which is a well-understood and bounded cost.

**Why deliberately leave the top face un-anodized?**
This is the least obvious decision on the part. Hard anodize raises emissivity from ~0.1 to ~0.8. Across the 1.5 mm choke gap at ΔT = 100 K, that changes radiative coupling from ~4 W to ~50 W — a parallel leak path that partially short-circuits the thermal choke and makes R_choke depend on temperature. Leaving the face bright preserves the choke as a nearly pure conduction element, which is what makes it predictable and tunable.

**Why are the choke fastener holes toleranced so loosely (⌖ Ø0.200)?**
Because they must be loose. The Heater Plate grows 0.4 mm radially relative to this plate across the operating range. Tight fastener holes would either over-constrain the joint (causing bow, FMEA #12 at assembly level) or shear the fasteners. The joint is located by the three kinematic locators and clamped by Belleville stacks; the fastener holes only need to not interfere.

## 13. Why Semiconductor Tools Use This Design

- **Liquid-cooled aluminum pedestals are the industry standard** in plasma etch and PECVD chambers from Lam, Applied Materials, and ASM. The reasons are the ones above: process heat loads of 1–5 kW must be removed with wafer-temperature stability of ±1 °C, and only a forced-convection liquid loop has both the capacity and the stability to do it.

- **Welded or brazed monolithic channels, never gasketed lids.** In a production chamber, a coolant leak into vacuum is a multi-day recovery and can scrap the chamber's ceramic parts. Every serious chuck vendor eliminates elastomers from the coolant pressure boundary. Friction stir welding in particular became widespread for exactly this application because it joins 6061 at full strength without filler, flux, or a molten pool that could contaminate the channel.

- **The cooled-base / thermal-break / heater topology is how every modern temperature-controlled ESC works.** Whether the heater is a discrete plate (as here), co-fired into the ceramic, or brazed into the base, the architecture is the same: a cold sink at a controlled temperature, a defined thermal resistance, and a heater that trims upward. Tools that omit the thermal break cannot control wafer temperature — the sink simply wins.

- **The pedestal is the RF electrode.** In capacitively-coupled plasma tools the wafer pedestal is the powered (bias) electrode, floating on ceramic standoffs from the grounded chamber, with the ESC dielectric acting as the coupling capacitor. Everything about the mechanical design — the insulating support ring, the isolated fasteners, the line breaks on every utility — follows from that one electrical fact.

- **Anodize masking discipline is a real production practice.** Semiconductor chuck drawings routinely carry a dedicated masking sheet because anodize simultaneously helps (plasma durability, dielectric protection) and hurts (thermal contact, electrical contact, particle shedding). Knowing *where not to anodize* is a signature of someone who has actually built one.

## 14. Interview Talking Points

1. **"I sized the coolant channel from Reynolds number, not pressure drop."** At 4 L/min through a 10 × 6 mm channel, velocity is 1.11 m/s and Re ≈ 8,300 — turbulent with margin. A larger channel would have given a nicer ΔP and quietly dropped the flow laminar, collapsing the convective coefficient and losing the ±1.5 °C uniformity requirement. Turbulence is a design requirement on this part, which is why there's a minimum-flow interlock at 2.5 L/min.

2. **"The masking drawing is as important as the machining drawing."** Five surfaces on this plate are excluded from hard anodize for three different reasons: the choke face and pads because anodize would triple radiative coupling and make contact conductance unpredictable, the RF land because anodize is a dielectric and the joint has to carry 13.56 MHz at under 0.5 mΩ, and the channel interior because flaking anodize fouls the heat exchanger. One missed mask turns a designed thermal choke into an unknown one.

3. **"No elastomer in the coolant pressure boundary."** A friction-stir-welded lid costs more than an O-ring-sealed one. But an O-ring separating pressurized glycol from high vacuum, over 100 thermal cycles, is a catastrophic-severity failure with a slow-degradation mechanism — the worst combination. I moved that risk from an in-service seal to a one-time manufacturing operation that I can radiograph, proof, and leak-test before the part ever ships.

4. **"I toleranced three features tight and everything else loose — on purpose."** Plate thickness, top-face flatness, and kinematic locator position are the only tight callouts, because those are the only features that propagate to the wafer plane or the chuck axis. The choke fastener holes are at ⌖ Ø0.200 because the Heater Plate moves 0.4 mm relative to this plate across the operating range — tight holes there would over-constrain the joint and bow the stack. Loose tolerances on that pattern aren't sloppiness, they're the constraint scheme.

5. **"Stress relief is called out twice and it isn't optional."** This is a 20 mm 6061 plate with a channel milled through most of its lower face. Machining it flat, then anodizing, then discovering 80 µm of bow at final inspection is the classic way to scrap the most expensive part in the stack. Rough machine, relieve, semi-finish, relieve, finish, and lap last — after anodize.

6. **"The routing of the coolant circuit is downstream of a wafer-quality decision."** Nothing penetrates the ESC top surface, so all 24 stack fasteners come from below, so the serpentine has to weave around a fixed fastener pattern. That's why the specification contains a keep-out table and instructs CAD to satisfy it before optimizing path length. Coupling like that has to be resolved at freeze; if you find it in CAD, you've already drawn the channel twice.

7. **"Loss of turbulence is a higher-probability failure than a leak."** People design chucks against the catastrophic case — coolant into vacuum — and control it well with welded construction and leak testing. The failure that actually bites you in the field is a partially blocked strainer or a degraded pump that drops flow to 2 L/min, goes transitional, and produces a slow, drifting wafer-uniformity problem that nobody attributes to the chiller for weeks. That's why flow and ΔP are interlocked and monitored, not just specified.

---

**END OF VOLUME 01**

*Next: Volume 02 — SEWCP-300 Heater Plate*

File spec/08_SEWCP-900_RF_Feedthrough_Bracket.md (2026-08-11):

# SEWCP-ENG-009 — RF Feedthrough Bracket Assembly

**Part Number:** SEWCP-900 · **Volume:** 08 of 09 · **Revision:** A
**Parent:** SEWCP-ENG-001 Architecture & ICD
**Sub-parts:** SEWCP-901 RF Strap · SEWCP-902 Strap Support Bracket · SEWCP-903 Terminal Hardware Set · SEWCP-904 Deposition Shroud
**Applicability:** Configuration A (RF-hot chuck) only. **In Configuration B (grounded chuck) this entire assembly is deleted.**

---

## 1. Engineering Purpose

This assembly carries 13.56 MHz bias power from the chamber-mounted RF vacuum feedthrough to the Cooling Plate, which is the powered bias electrode.

It looks like a bracket. It is actually **a length of transmission line with a mechanical support**, and every requirement on it is electrical:

1. **Carry RF current with minimum loss.** At 13.56 MHz, current flows in the outer ~18 µm of the conductor, so surface geometry — not cross-sectional area — determines resistance.
2. **Present minimum series inductance.** Any reactance between the match network and the electrode shifts the match point, wastes power, and makes tuning drift with temperature.
3. **Hold that inductance constant.** Inductance is a function of geometry. If the strap can move, the impedance of the RF path moves with it, and the plasma changes. **The bracket's primary function is to make the strap's geometry repeatable and immovable.**
4. **Maintain isolation from ground** — clearance, creepage, and immunity to process deposition building a conductive path.
5. **Provide a low-resistance, stable bolted joint** at the electrode. A degrading RF joint is a thermal-runaway mechanism, not merely a loss.
6. **Absorb thermal and assembly movement** without transmitting load into the chuck or the ceramic support ring.

## 2. Functional Requirements

| ID | Requirement | Value | Verification |
|---|---|---|---|
| RF-01 | Frequency | 13.56 MHz | — |
| RF-02 | Power handling | ≤ 1000 W forward | — |
| RF-03 | Peak voltage | ≤ 1500 V | — |
| RF-04 | RMS current capability | ≥ 40 A | Analysis + thermal test |
| RF-05 | **Series inductance, feedthrough to electrode** | **≤ 35 nH** | Network analyser |
| RF-06 | **Inductance repeatability after service** | **±5%** | Network analyser, before/after |
| RF-07 | Strap AC resistance | ≤ 3 mΩ | 4-wire at frequency / calculation |
| RF-08 | **Terminal joint contact resistance** | **≤ 0.5 mΩ** | 4-wire micro-ohmmeter |
| RF-09 | Clearance to ground, vacuum side | ≥ 8 mm (with DR-11 in force) | Drawing + inspection |
| RF-10 | Clearance to ground, atmosphere side | ≥ 12 mm | Drawing |
| RF-11 | Creepage over any solid surface | ≥ 20 mm | Drawing |
| RF-12 | Compliance travel, all axes | ≥ ±3 mm at ≤ 5 N reaction | Force gauge |
| RF-13 | Base Plate pass-through | Clearance only, ≥ 2 mm radial (DR-1) | Drawing |
| RF-14 | Maximum strap temperature rise at rated power | ≤ 20 K | Thermal test |
| RF-15 | Outgassing | < 1×10⁻⁷ Torr·L/s·cm² at 150 °C | RGA |

### 2.1 Skin Effect — Why the Conductor Is a Strap

Skin depth **δ = √(ρ / π f µ)** at 13.56 MHz:

| Material | ρ (Ω·m) | µ_r | δ | Surface resistance R_s = ρ/δ |
|---|---|---|---|---|
| **Silver** | 1.59×10⁻⁸ | 1 | **17.2 µm** | **9.23×10⁻⁴ Ω/sq** |
| **Copper (OFHC)** | 1.68×10⁻⁸ | 1 | **17.7 µm** | **9.49×10⁻⁴ Ω/sq** |
| **Nickel** | 6.99×10⁻⁸ | ~100 | **3.6 µm** | **1.94×10⁻² Ω/sq** |

**Nickel is 20× more resistive per square than copper at this frequency.** It is both more resistive *and* ferromagnetic, so its skin depth collapses and the current is forced into a thin, lossy layer.

Because current occupies only the outer ~18 µm, **conductor perimeter determines resistance, not area**:

| Conductor | Perimeter | AC resistance over 150 mm |
|---|---|---|
| Ø10 mm round rod | 31.4 mm | 4.5 mΩ |
| **50 × 0.5 mm strap** | **101 mm** | **1.4 mΩ** |

The strap has 3.2× the conducting perimeter of the rod at less than one-third of the mass.

**Loss check:** at 40 A RMS, P = I²R = 1600 × 1.4×10⁻³ = **2.2 W** — trivially handled.
**Joint check:** the same 40 A through a degraded 10 mΩ joint dissipates **16 W into a contact patch a few square millimetres in area.** That is the failure mechanism that matters (§11 FM #1), and it is why RF-08 is specified at 0.5 mΩ.
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

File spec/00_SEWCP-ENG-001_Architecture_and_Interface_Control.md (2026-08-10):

# SEWCP-ENG-001 — Architecture & Interface Control Document

**Program:** Simplified Electrostatic Wafer Chuck Platform (SEWCP)
**Volume:** 00 of 09 — Architecture, Datums, Budgets, Interface Control
**Revision:** A (Specification Freeze Candidate)
**Date:** 2026-08-07
**Prepared by:** Lead Mechanical Design Engineer
**Status:** FOR SPECIFICATION FREEZE — CAD release authorized against this baseline

---

## 1. Scope and Purpose

This document set defines the complete engineering specification for all SEWCP components **except the Base Plate, which is frozen and shall not be redesigned.** The specification is written to a level of detail sufficient that CAD may be executed directly, without design iteration.

This volume (00) establishes the shared framework — coordinate system, datums, stack-up, thermal/RF/vacuum budgets, tolerance allocation, fastener schedule, master assembly sequence, and interface control. Volumes 01–09 specify each component against this framework.

**No CAD, no modeling steps, and no code are contained in this document set.** This is engineering documentation only.
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

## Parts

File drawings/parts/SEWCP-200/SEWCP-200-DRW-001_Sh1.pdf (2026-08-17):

## NOTES:

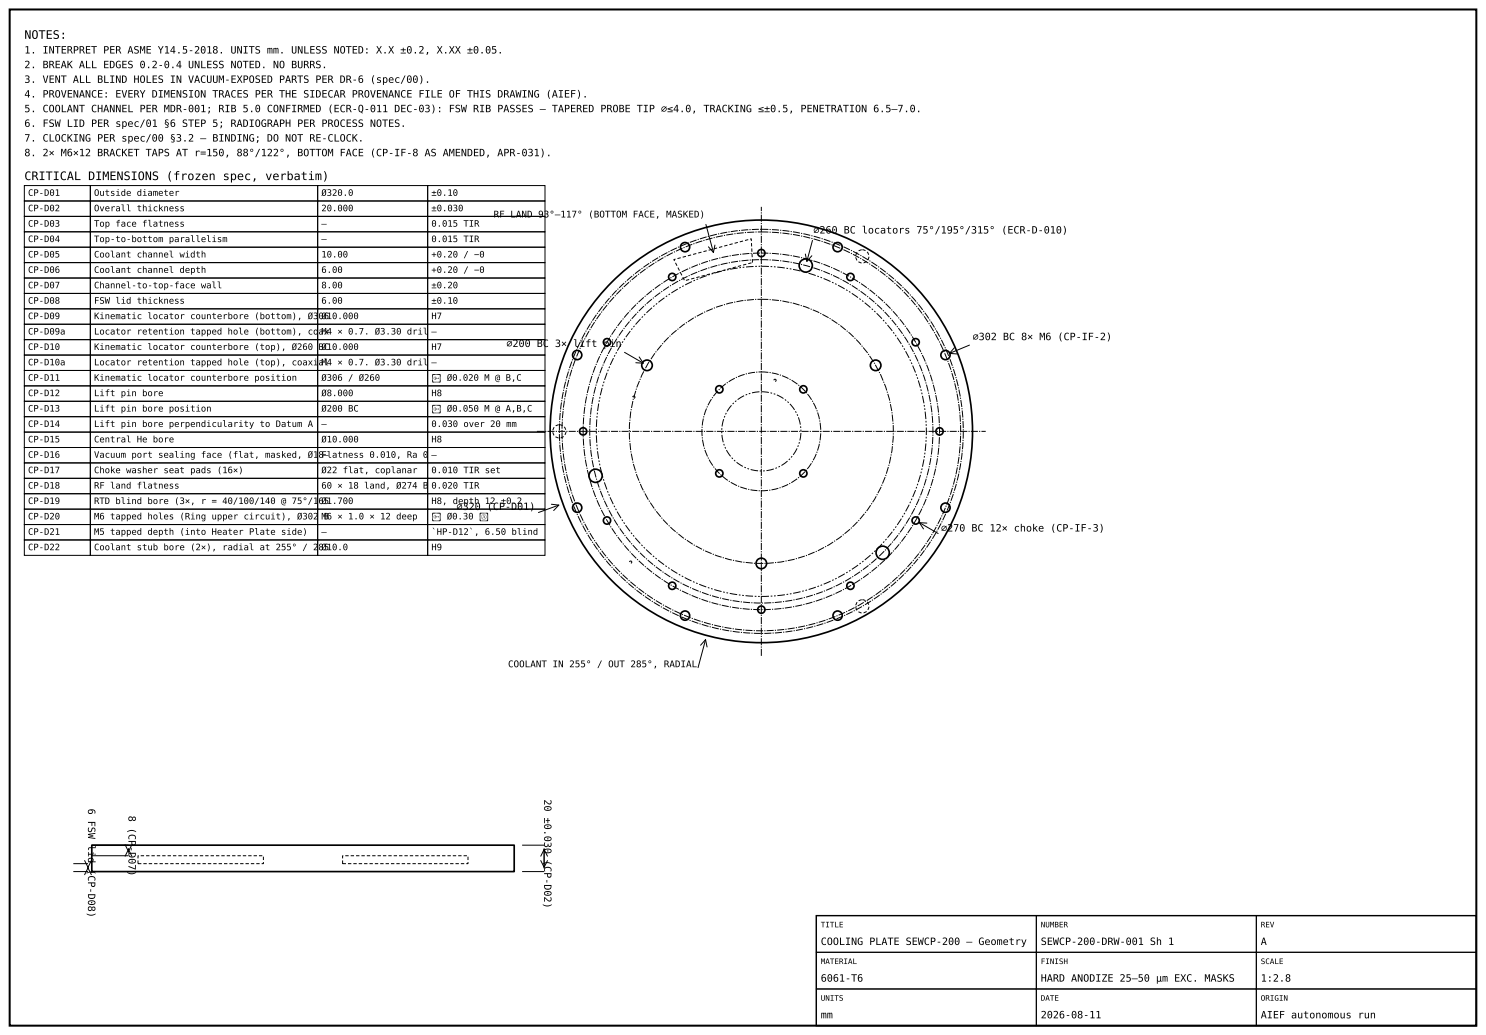
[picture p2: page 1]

1. INTERPRET PER ASME Y14.5-2018. UNITS mm. UNLESS NOTED: X.X ±0.2, X.XX ±0.05.
2. BREAK ALL EDGES 0.2-0.4 UNLESS NOTED. NO BURRS.
3. VENT ALL BLIND HOLES IN VACUUM-EXPOSED PARTS PER DR-6 (spec/00).
4. PROVENANCE: EVERY DIMENSION TRACES PER THE SIDECAR PROVENANCE FILE OF THIS DRAWING (AIEF).
5. COOLANT CHANNEL PER MDR-001; RIB 5.0 CONFIRMED (ECR-Q-011 DEC-03): FSW RIB PASSES — TAPERED PROBE TIP ⌀≤4.0, TRACKING ≤±0.5, PENETRATION 6.5–7.0.
6. FSW LID PER spec/01 §6 STEP 5; RADIOGRAPH PER PROCESS NOTES.
7. CLOCKING PER spec/00 §3.2 — BINDING; DO NOT RE-CLOCK.
8. 2× M6×12 BRACKET TAPS AT r=150, 88°/122°, BOTTOM FACE (CP-IF-8 AS AMENDED, APR-031).

CRITICAL DIMENSIONS (frozen spec, verbatim)

CP-D01 | Outside diameter | Ø320.0 | ±0.10
CP-D02 | Overall thickness | 20.000 | ±0.030
CP-D03 | Top face flatness | — | 0.015 TIR
CP-D04 | Top-to-bottom parallelism | — | 0.015 TIR
CP-D05 | Coolant channel width | 10.00 | +0.20 / −0
CP-D06 | Coolant channel depth | 6.00 | +0.20 / −0

RF LAND 93°–117° (BOTTOM FACE, MASKED)

⌀260 BC locators 75°/195°/315° (ECR-D-010)

CP-D07 | Channel-to-top-face wall | 8.00 | ±0.20
CP-D08 | FSW lid thickness | 6.00 | ±0.10
CP-D09 | Kinematic locator counterbore (bottom), Ø306Ø10.000 | | H7
CP-D09a | Locator retention tapped hole (bottom), coaxM4 × 0.7. Ø3.30 dril | | —

CP-D10 | Kinematic locator counterbore (top), Ø260 | BCØ10.000 | H7
CP-D10a | Locator retention tapped hole (top), coaxialM4 × 0.7. Ø3.30 dril | | —

⌀200 BC 3× lift pin

CP-D11 | Kinematic locator counterbore position | Ø306 / Ø260 | ⌖ Ø0.020 M @ B,C

CP-D12 | Lift pin bore | Ø8.000 | H8
CP-D13 | Lift pin bore position | Ø200 BC | ⌖ Ø0.050 M @ A,B,C
CP-D14 CP-D15 | Lift pin bore perpendicularity to Datum A Central He bore | — Ø10.000 | 0.030 over 20 mm H8

CP-D16 | Vacuum port sealing face (flat, masked, Ø18Flatness 0.010, Ra 0 – | | —

CP-D17 | Choke washer seat pads (16×) | Ø22 flat, coplanar | 0.010 TIR set
CP-D18 | RF land flatness | 60 × 18 land, Ø274 B | 0.020 TIR
CP-D19 | RTD blind bore (3×, r = 40/100/140 @ 75°/165Ø1.700 | | H8, depth 12 ±0.2 ⌀320 (CP-D01)
CP-D20 | M6 tapped holes (Ring upper circuit), Ø302 | BM6 × 1.0 × 12 deep | ⌖ Ø0.30 Ⓜ
CP-D21 | M5 tapped depth (into Heater Plate side) | — | `HP-D12`, 6.50 blind

⌀270 BC 12× choke (CP-IF-3)

CP-D22 | Coolant stub bore (2×), radial at 255° / 285Ø10.0 | | H9

COOLANT IN 255° / OUT 285°, RADIAL 20 ±0.030 (CP-D02)

6 FSW lid (CP-D08)

TITLE COOLING PLATE SEWCP-200 — Geometry | NUMBER SEWCP-200-DRW-001 Sh 1 | REV A

MATERIAL 6061-T6 | FINISH HARD ANODIZE 25–50 µm EXC. MASKS | SCALE 1:2.8

UNITS mm | DATE 2026-08-11 | ORIGIN AIEF autonomous run

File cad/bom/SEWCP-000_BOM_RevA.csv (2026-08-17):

level | part_number | name | qty | material | spec_source | cad_state | deliverable | notes
0 | SEWCP-000 | MASTER ASSEMBLY | 1 | — | spec/00 §4 / §10 | Fusion assembly (cloud) | cad/exports/step/SEWCP-000_MASTER_ASSEMBLY.step | 19 occurrences, verified ASSEMBLY_S-2026-08-11-05 PASS
1 | SEWCP-200 | COOLING PLATE | 1 | 6061-T6 | spec/01 §7 | verified model (SEWCP-200_COOLING_PLATE) | cad/exports/step/SEWCP-200_COOLING_PLATE.step, cad/exports/stl/SEWCP-200_COOLING_PLATE.stl | Hard anodize exc. masks; lineage re-homed 2026-08-11 (stuck cloud derivative) - REPAIRS_S-2026-08-11-04
1 | SEWCP-300 | HEATER PLATE | 1 | 6061-T6 | spec/02 §6 | verified model (SEWCP-300_HEATER_PLATE) | cad/exports/step/SEWCP-300_HEATER_PLATE.step, cad/exports/stl/SEWCP-300_HEATER_PLATE.stl | Clean; no anodize on bond face
1 | SEWCP-400 | SUPPORT RING | 1 | Al2O3 99.5% | spec/03 §7 | verified model (SEWCP-400_SUPPORT_RING) | cad/exports/step/SEWCP-400_SUPPORT_RING.step, cad/exports/stl/SEWCP-400_SUPPORT_RING.stl | As-fired; lapped at assy
1 | SEWCP-500 | ESC PUCK | 1 | Al2O3 99.6% | spec/04 §6 | verified model (SEWCP-500_ESC_PUCK) | cad/exports/step/SEWCP-500_ESC_PUCK.step, cad/exports/stl/SEWCP-500_ESC_PUCK.stl | Lapped top; mesa process
1 | SEWCP-600 | LIFT PIN | 3 | Al2O3 99.8% | spec/05 §6 | verified model (SEWCP-600_LIFT_PIN) | cad/exports/step/SEWCP-600_LIFT_PIN.step, cad/exports/stl/SEWCP-600_LIFT_PIN.stl | Ground; Ra ≤ 0.2 tip/shaft
1 | SEWCP-700 | ALIGNMENT PIN | 6 | Ti-6Al-4V | spec/06 §6 | verified model (SEWCP-700_ALIGNMENT_PIN) | cad/exports/step/SEWCP-700_ALIGNMENT_PIN.step, cad/exports/stl/SEWCP-700_ALIGNMENT_PIN.stl | Dry film + passivate
1 | SEWCP-800 | PORT BODY | 1 | 316L SST | spec/07 §6 | verified model (SEWCP-800_PORT_BODY) | cad/exports/step/SEWCP-800_PORT_BODY.step, cad/exports/stl/SEWCP-800_PORT_BODY.stl | Electropolish wetted
1 | SEWCP-901 | RF STRAP | 1 | C10100 OFHC | spec/08 §6 | verified model (SEWCP-901_RF_STRAP) | cad/exports/step/SEWCP-901_RF_STRAP.step, cad/exports/stl/SEWCP-901_RF_STRAP.stl | Ag 8-13 µm direct (DR-7)
1 | SEWCP-902 | SADDLE | 1 | 6061-T6 | spec/08 §5.2 | verified model (SEWCP-902_SADDLE) | cad/exports/step/SEWCP-902_SADDLE.step, cad/exports/stl/SEWCP-902_SADDLE.stl | Alodine 1200
1 | SEWCP-1000 | RETAINER | 3 | 6061-T6 | spec/09 §6 | verified model (SEWCP-1000_RETAINER) | cad/exports/step/SEWCP-1000_RETAINER.step, cad/exports/stl/SEWCP-1000_RETAINER.stl | Alodine 1200
1 | SEWCP-301 | Thermal choke washer, Ti, 1.50 thk | 16 | Ti Grade 2 | spec/00 §4.2 row 3; spec/01 CP-IF-3 | spec-only | - | Unmodelled by CP package decision: choke pads are treatment zones; the washer supplies the 1.50 gap represented in the assembly.
1 | SEWCP-401 | Support ring clamp ring | 1 | 316L | spec/03 §5.2 | spec-only | - | Material corrected 6061-T6 -> 316L per ECR-Q-014: the old row cited spec/00 §9 and SR-IF-2, neither of which states a material, while spec/03 §5.2 heads the part '(316L)'. Geometry deferred, and per ECR-D-016 the tabulated Ø318.0/Ø286.0 form cannot be placed at all - it intersects the web. Rev B item.
1 | SEWCP-601 | Lift pin bushing, bore Ø5.60 +0.05/−0 | 3 | Vespel/PEEK per spec/05 | spec/05 LB-D01 (ECR-Q-009 corrected) | spec-only | - | Deferred geometry (drawing-stage register).
1 | SEWCP-903 | RF terminal hardware set (4× M6×16 Ag SHCS, 4× Ø16 Ag washers, 4× Belleville stacks) | 1 | A4-70 / Ag plated | spec/08 §5.3 | spec-only | - | Hardware set; 6.0 N·m; spec-only.
1 | SEWCP-904 | Deposition shroud | 1 | Ceramic per spec/08 | spec/08 §5.4 | spec-only | - | NO dimensional authority in spec/08 - requirement gap, carried (drawing-stage register); not modelled, not drawn.
1 | HW-M640SHCS | M6 × 40 SHCS — Lower circuit: Base Plate ↔ Support Ring bottom flange ↔ SEW | 8 | A4-70 | spec/00 §9 (verbatim) | spec-only | - | torque 6.0 N·m; Ø16 flat + Belleville stack
1 | HW-M616SHCS | M6 × 16 SHCS — Upper circuit: Support Ring top flange ↔ Cooling Plate | 8 | A4-70 | spec/00 §9 (verbatim) | spec-only | - | torque 6.0 N·m; Ø16 flat + Belleville stack
1 | HW-M525SHCS | M5 × 25 SHCS — Cooling Plate ↔ Heater Plate (outer choke) | 12 | A4-70 | spec/00 §9 (verbatim) | spec-only | - | torque 3.5 N·m; Ti washer + Belleville
1 | HW-M525SHCS | M5 × 25 SHCS — Cooling Plate ↔ Heater Plate (inner choke) | 4 | A4-70 | spec/00 §9 (verbatim) | spec-only | - | torque 3.5 N·m; Ti washer + Belleville
1 | HW-M416SHCS | M4 × 16 SHCS — Vacuum Port flange | 4 | A4-70 | spec/00 §9 (verbatim) | spec-only | - | torque 1.8 N·m; Flat
1 | HW-M616SHCS | M6 × 16 SHCS — RF strap to Cooling Plate land | 2 | A4-70, silver-plated | spec/00 §9 (verbatim) | spec-only | - | torque 6.0 N·m; Silver-plated flat + Belleville
1 | HW-M620SHCS | M6 × 20 SHCS — RF bracket clamp to Base Plate | 2 | A4-70 | spec/00 §9 (verbatim) | spec-only | - | torque 6.0 N·m; Flat
1 | HW-M412SHCS | M4 × 12 SHCS — Temp sensor bracket | 4 | A4-70 | spec/00 §9 (verbatim) | spec-only | - | torque 1.8 N·m; Flat
1 | SEWCP-100 | BASE PLATE (frozen reference) | REF | — | spec/00 §2 FBA | frozen — not part of deliverable set | - | Datum A reference; excluded from the assembly by DR-1

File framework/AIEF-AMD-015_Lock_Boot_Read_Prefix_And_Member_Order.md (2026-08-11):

# AIEF-AMD-015 — Architecture Amendment: the Lock's Measured Quantity is the Boot-Read Prefix, and `aggregate_digest` Moves to Second Position

| | |
|---|---|
| **Instrument** | Architecture amendment to AIEF 1.0.0, partition `framework` |
| **Amends** | `framework/framework.manifest.json` — **three** changes: two normative clause bodies and one authority citation |
| **Disposes** | `ECR-D-014` |
| **Raises** | `OI-C-14` |
| **Authorising basis** | The human owner's written instruction of 2026-08-11: *"If a software/architecture gap exists: repair it at the owning layer. Test it. Verify it. Continue."* — `core/PRECEDENCE.md` rank 1, recorded per LAW-10 in `project/approvals/APR-035` and `project/approvals/APR-036` |
| **Authority exercised by** | `claude-under-owner-delegation · S-2026-08-11-06`. **OWNER-DELEGATED ENGINEERING AUTHORITY EXERCISED BY CLAUDE — this is not a human approval and is never to be cited as one** |
| **Provenance record** | [`../.ai/project/decisions/DECISIONS_S-2026-08-11-06.md`](../.ai/project/decisions/DECISIONS_S-2026-08-11-06.md) DEC-06 |

---

## Why this instrument exists

The first authorised Compiler Stage 6 build **halted**, and it halted correctly:

```
aief_stage6.budget.BudgetBreach: core/MANIFEST.lock: governing 6481 > cap 200 - build halts
```

The halt was not a bug. `budget_measurement_record.verdict_rule` requires it, and the
implementation obeyed the clause it was written from. The defect is that the clause it obeyed and
another clause of the same artifact cannot both hold, and the one it obeyed is unsatisfiable by
any conforming lock. `ECR-D-014` records the finding, the measurements and the rejected
alternatives; this instrument makes the ruling.

**Nothing about integrity changes here.** The lock still carries every covered file and its DC-1
digest, `aggregate_digest` is still DC-4 over exactly those records, B2a still recomputes all of
it, and the BINDING pin still binds the aggregate. What changes is which octets a token cap
counts, and where one member sits in a JSON document.

---

## AMD-54 — The Measured Quantity is the Boot-Read Prefix

**Amends** `metadata.reproducible.budget_measurement_record.lock_self_measurement` ·
**Disposes** `ECR-D-014` in part · **Raises** `OI-C-14`

### 1 · The gap

`AIEF-AMD-013` §AMD-45 declared *"the serialised lock octets are measured under both families
against the 200 cap after serialisation"*. It settled **when** the measurement happens
(post-serialisation, before the archive), **under what** (both families), and **what a breach
does** (halts). It did not settle **which octets**, and the natural reading — all of them — is
unsatisfiable.

Measured at `S-2026-08-11-06` with both declared tokenizer artifacts in hand:

| Quantity | TF-1 | TF-2 | vs 200 |
|---|---|---|---|
| Whole serialised lock | 5334 | **6469** | 32.3× |
| `files` alone (75 pairs) | 4212 | 5198 | 26.0× |
| Schema-required members, `files` removed | — | 285 | 1.4× |
| **Boot-read prefix, after §AMD-55** | **56** | **69** | **0.35×** |

The third row is the one that decides it: **even a lock stripped of `files` and
`budget_measurement` breaches 200.** No content reduction reaches the cap, and
`AIEF-AMD-013` §AMD-41 §5(iii)'s finding forecloses raising it — MI-4 stands at 5904 of 6000 and
a raise to 6469 would put the sum at 12173.

### 2 · What the other clause already said

`digest_constructions.core_aggregate.lock_serialisation`, unchanged since `AIEF-AMD-010` §AMD-27:

> *"aggregate_digest precedes files **so the T1 digest read stays within the 200-token cap**
> declared on files[manifest-lock]"*

This is a normative statement that the cap bounds **a read that stops at `aggregate_digest`**.
It is the only reading under which member ordering can bear on the count at all; under the
whole-document reading, ordering is irrelevant to the total and the clause states a purpose it
cannot serve. The two clauses have been in contradiction since AMD-45 was written, and nothing
executed the pair until now.

### 3 · Ruling

**The octets measured against `files[manifest-lock].token_cap` are the boot-read prefix: the
serialised lock from its first octet through the terminal LF of the line carrying the
`aggregate_digest` member.**

Everything else of AMD-45 is unchanged and is restated so nothing is read as relaxed:

| Property | Status |
|---|---|
| Measurement is post-serialisation, before the archive is built | **unchanged** |
| Both families, the maximum governs | **unchanged** |
| A breach halts the build under `verdict_rule` | **unchanged** |
| The lock's per-file row is `DEFERRED-SELF-MEASURED`, null counts, contributing nothing to totals | **unchanged** |
| The deferral is keyed on the path `core/MANIFEST.lock`, never on absence from the tree | **unchanged** (TCR-001 F1 stays disposed) |
| `AIEF-AMD-014` §AMD-51 charges the **full declared 200** to each per-family total | **unchanged** — the charge is the declared cap, not the measurement, so the aggregate comparison still over-states and never under-states |

**The prefix has no fallback.** A serialised lock with no `aggregate_digest` line, or one whose
`aggregate_digest` line is not LF-terminated, has no boot-read prefix, and the build **halts**. A
fallback to some other region is how a cap comes to bound a quantity nobody declared, which is
the defect class this instrument exists to close, not to repeat.

### 4 · Why this quantity, and not a convenient one

`b2a_procedure` is a machine procedure over file content: recompute DC-1 per listed file,
recompute DC-4, compare to `aggregate_digest`, compare that to `BINDING.core_digest_pin`. The 75
digests are **hashed**, not read. `measurement_domain` binds the measured set to *"the domain of
manifest invariant MI-4 … and of the AIEF-FRZ-001 §1.8 derivation table"* — the boot **context**
budget, which is what a reader must load. The prefix is exactly what a reader loads before it
holds the value B2a compares to the pin. A list of 75 digests was never boot context, and
`lock_serialisation` said as much in the only words it had.

### 5 · Residual — `OI-C-14`, raised and expressly not cured

**The whole-document size of `core/MANIFEST.lock` is now bounded by nothing.** 6469 TF-2 tokens
today, growing with the covered set. No invariant ranges over it and nothing is violated — but
*nothing is violated* is not *something is checked*, which is the `OI-V-02` lesson. Raised as
`OI-C-14`, for an authority that can weigh a whole-document bound against the artifact's purpose.
Not cured here: inventing a second, undeclared cap while disposing a defect about an undeclared
measured quantity would be the same mistake twice.

### 6 · Manifest change

`metadata.reproducible.budget_measurement_record.lock_self_measurement` — the existing text is
retained **verbatim and entire**, and the ruling is appended to it. Nothing AMD-45 wrote is
deleted or reworded.

---

## AMD-55 — `aggregate_digest` Moves to Second Position

**Amends** `metadata.reproducible.digest_constructions.core_aggregate.lock_serialisation` ·
**Disposes** `ECR-D-014` in part

### 1 · Why the ordering is not cosmetic

With §AMD-54 alone and the member order unchanged, the prefix is:

```
{ framework_version, build_provenance{ source_manifest, source_manifest_dc1,
  selected_profile, compiler_stage, build_id, timestamp }, hash_algorithm,
  normalisation{ 4 members }, aggregate_digest }
```

— **291 tokens under TF-2 against a 200 cap.** It would still breach, and the only cap value MI-4
admits is 296, which fits by five tokens and consumes every one of the 96 tokens of headroom
`AIEF-AMD-014` §AMD-50 left.

Worse than tight: **that prefix contains `build_id`**, and `build_provenance_record.content.build_id`
bounds its length not at all. Measured across identifier lengths:

| `build_id` length | 1 | 8 | 27 | 52 | 80 |
|---|---|---|---|---|---|
| Prefix, TF-2 | 280 | 282 | 291 | 306 | 319 |

A cap over that quantity is a cap over a free-form string. It would pass on the release run that
set it and fail on the next one that named its build differently — a check that depends on what
someone types is not a check.

### 2 · Ruling

**Declared member order becomes: `framework_version`, `aggregate_digest`, `build_provenance`,
`hash_algorithm`, `normalisation`, `budget_measurement`, `files`.** `aggregate_digest` moves from
fifth position to second.

The clause *"aggregate_digest precedes files"* is unchanged in words and was already satisfied.
What it could not do at the fifth position was deliver the property it states as its reason.

Resulting prefix:

```json
{
  "framework_version": "1.0.0",
  "aggregate_digest": "<64 lowercase hex>",
```

**69 tokens under TF-2, 56 under TF-1.** Determined entirely by the specification: no `build_id`,
no `timestamp`, no profile name, nothing a caller chooses. A 2.9× margin against the cap, and the
margin does not move when a release run names itself differently.

### 3 · What this does not disturb

| | |
|---|---|
| `files[manifest-lock].token_cap` | **200, unchanged** |
| MI-4 | **5904 of 6000, unchanged. Headroom 96, unchanged** |
| `AIEF-FRZ-001` §1.8 derivation | **unchanged** |
| `version.min_context_window` | **unchanged** — the ratified 32,000-token portability floor is not touched, so OQ-15 option (b)'s cost is not incurred |
| `sch-core-manifest` | **unchanged.** It declares required *fields*, not their order; the emitted lock validates against the emitted schema, and a test asserts it |
| DC-4, `aggregate_digest`'s value, the covered set, `b2a_procedure` | **unchanged** |
| `lock_json_layout` (AMD-43) | **unchanged**, and it is what makes this well-defined: *"Declared member order is emission order and is never sorted"*, one member per line, LF endings |
| Any existing digest | **none.** No `core/MANIFEST.lock` had ever been emitted, so no DC-5 release digest, no `core_digest_pin` and no archive existed to invalidate. The reorder is free precisely because it is being made before the first canonical build, and it could not have been made cheaply after |

### 4 · Manifest change

`…core_aggregate.lock_serialisation` — the member-order list is amended and the amendment is
appended with its reason and its measurements. The `aggregate_digest precedes files` clause and
the `files is an array of [path, digest] pairs in DC-4 record order` clause are retained verbatim.

---

## Blast Radius

Determined by inspecting what renders or consumes each changed clause, following the
AMD-008/009/012/013/014 method.

| Changed | Rendered or consumed by | Effect |
|---|---|---|
| `lock_self_measurement` | `src/aief_stage6/budget.py` (`measure_text`), `src/aief_stage6/build.py` | **Implementation delta, performed here.** `measure_text` now receives the prefix; `lock.boot_read_prefix` computes it and halts when it is undefined |
| `lock_serialisation` member order | `src/aief_stage6/lock.py` (`build_lock_object`) | **Implementation delta, performed here.** Insertion order is emission order per `lock_json_layout` |
| Both | `tests/test_stage6_certification_lock_archive_guard.py` | **Test delta, performed here.** The transcribed `LOCK_MEMBER_ORDER` constant is replaced by a parse of the clause itself, so the test tracks the ruling rather than a snapshot of it — the `OI-C-12` / `R-017` repair-at-the-property precedent. Four tests added for §AMD-54 |
| Neither | `.ai/core/**` | **None.** No `core/` artifact renders either clause. `core/CONTEXT_TIERS.md` renders the cap **table**, and no cap changes, so it does **not** become stale — unlike `AIEF-AMD-014` §AMD-50, which did stale it |
| Neither | `core/validation/CHECKS.md`, `MANIFEST` | **None.** `validation[V-09].verifies` is **not** amended: it already points at `lock_self_measurement` by name (*"the lock's own row follows lock_self_measurement"*), so the pointer carries the new content without a text change. `OI-V-07` is **not** deepened by this instrument |
| Neither | `adapters/ADP-ci.md` | **None.** Check count unchanged at 25 |
| Neither | `project/FROZEN.md` | Manifest row re-registered at the new DC-1; this instrument added under the AMD-21 criterion. Registry edit under `APR-035`/`APR-036` |

**Deliberately not touched:** every `.ai/core/**` byte except the canonical `core/MANIFEST.lock`
that Stage 6 is authorised to emit · `.ai/adapters/**` · `spec/**` and every CAD artifact,
drawing, BOM and deliverable — **no verified geometry is affected by this instrument in any way**
· `AIEF-FRZ-001`, AMD-001…AMD-014, both ADRs, every schema · `version.*` · any `token_cap` ·
git author or committer identity, and no attribution trailer of any kind is written anywhere.

---

## Separation of Duties — Recorded Tension

`core/agents/INDEX.md`: **`chief-systems-engineer` may not implement what it approved.** This
instrument was written, ruled, applied to the manifest, implemented in `src/aief_stage6/**` and
tested by **one session**, `S-2026-08-11-06`, under the owner's written delegation
(`core/PRECEDENCE.md` rank 1, which outranks the rank-6 agent specification). This is a **wider**
departure than AMD-013's and AMD-014's, both of which expressly **declined** to implement what
they ruled and left the delta to an A1 role as `OI-C-09`.

| | |
|---|---|
| Duty separated | A4 rules and approves; A1 implements; a distinct session verifies |
| Departure | One session ruled, applied, implemented and tested |
| Authority | The owner's written instruction of 2026-08-11, rank 1: *"repair it at the owning layer. Test it. Verify it. Continue."* — which directs the implementation expressly |
| Mitigating control | **NOT EXECUTED, and open.** An independent cold-context `qa-engineer` audit of this session's work is owed. It must independently re-measure the six quantities of §AMD-54 §1 under both families, re-derive the §AMD-55 prefix, and re-attack the four §AMD-54 tests |
| Not mitigated by | Anything this document says about itself. Under LAW-05 an authority's assertion about its own work carries no evidentiary weight — **including its assertion that the boot-read prefix measures 69** |

Recorded at `SOD-1` and at `OI-V-13`.

---

## Approvals Required and Recorded

| Change | Approval | Bound to |
|---|---|---|
| The manifest amendment of AMD-54 and AMD-55, and re-registration of the manifest in `FROZEN.md` at its post-change digest | `project/approvals/APR-035` | the post-change manifest DC-1 (`subject_hash`), with the pre-change DC-1 as `prior_hash` — both measured this session |
| Freeze-registry addition of this document (AMD-21 criterion) | `project/approvals/APR-036` | this document's DC-1 |

Per the AMD-16 design property, neither this document's own digest nor the post-registration DC-2
aggregate appears in this document; both live in the registry and the approval artifacts.

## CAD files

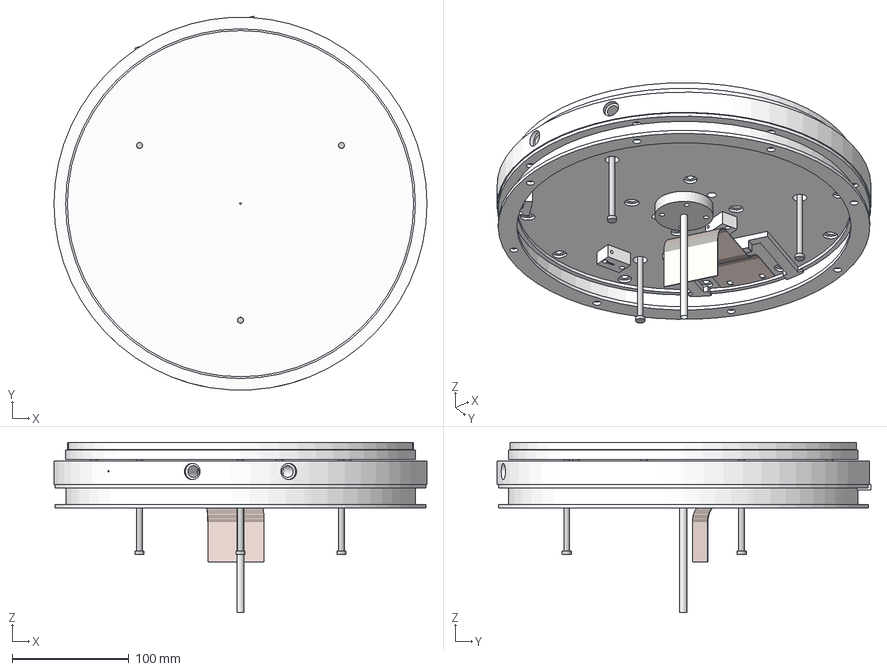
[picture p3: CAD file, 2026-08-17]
cad/exports/step/SEWCP-000_MASTER_ASSEMBLY.step
320.0 x 320.7 x 145.9 mm
SEWCP-400_SUPPORT_RING
SEWCP-300_HEATER_PLATE
SEWCP-500_ESC_PUCK
SEWCP-600_LIFT_PIN x 3
SEWCP-700_ALIGNMENT_PIN x 6
SEWCP-800_PORT_BODY
SEWCP-1000_RETAINER x 3
SEWCP-200_COOLING_PLATE
SEWCP-901_RF_STRAP
SEWCP-902_SADDLE

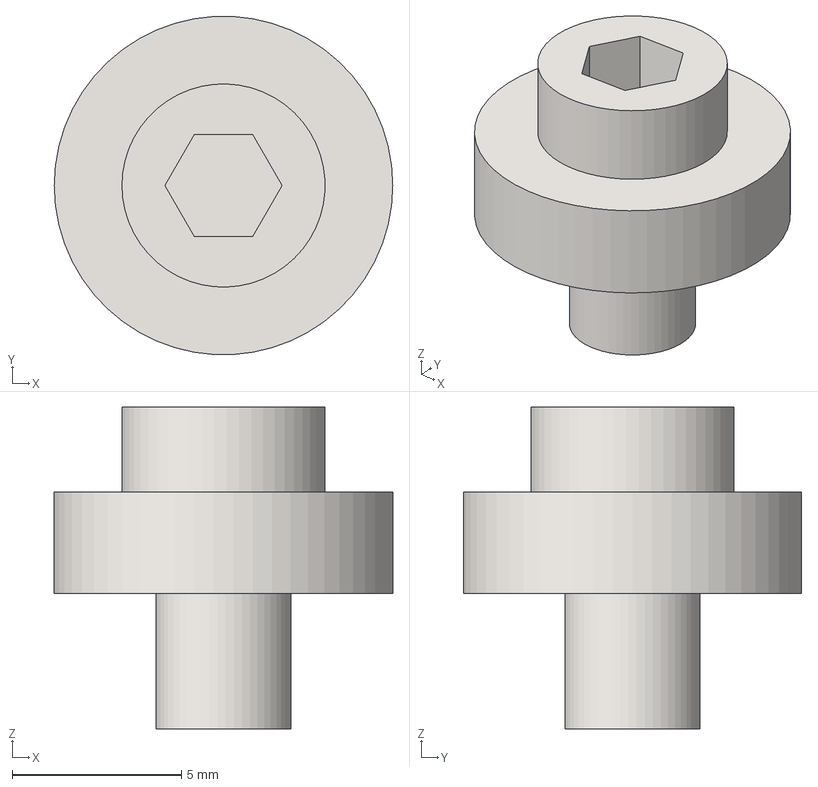
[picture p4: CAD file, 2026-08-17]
cad/exports/step/SEWCP-700_ALIGNMENT_PIN.step
10.0 x 9.98 x 9.50 mm

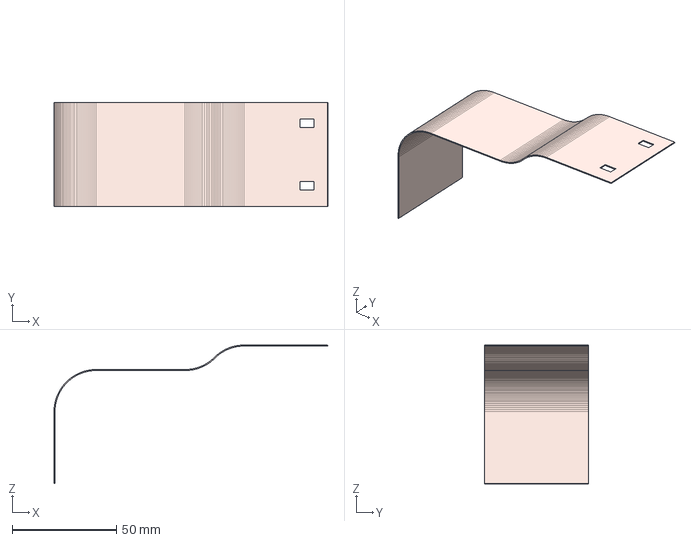
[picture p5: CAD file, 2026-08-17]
cad/exports/step/SEWCP-901_RF_STRAP.step
131.5 x 50.0 x 66.7 mm

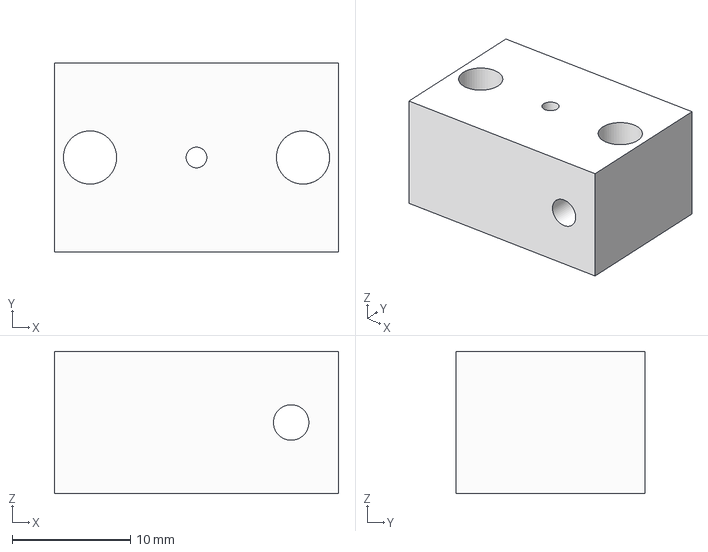
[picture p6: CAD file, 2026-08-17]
cad/exports/step/SEWCP-1000_RETAINER.step
24.0 x 16.0 x 12.0 mm

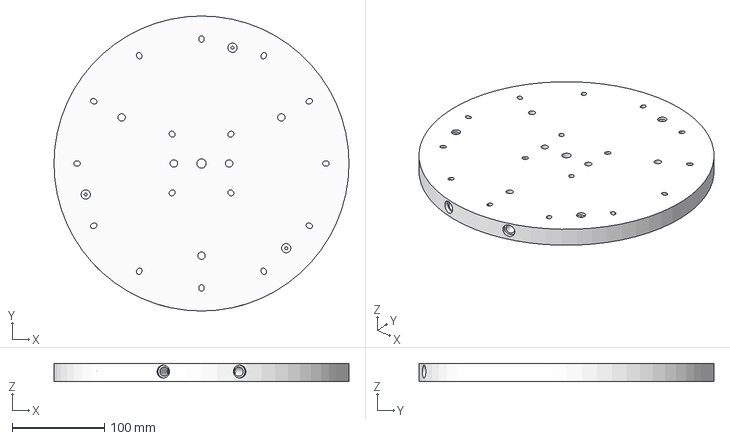
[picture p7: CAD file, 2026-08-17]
cad/exports/step/SEWCP-200_COOLING_PLATE.step
320.0 x 320.0 x 20.0 mm

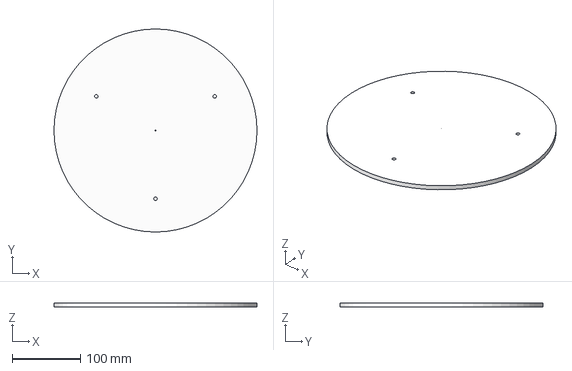
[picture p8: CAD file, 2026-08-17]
cad/exports/step/SEWCP-500_ESC_PUCK.step
297.0 x 297.0 x 6.00 mm

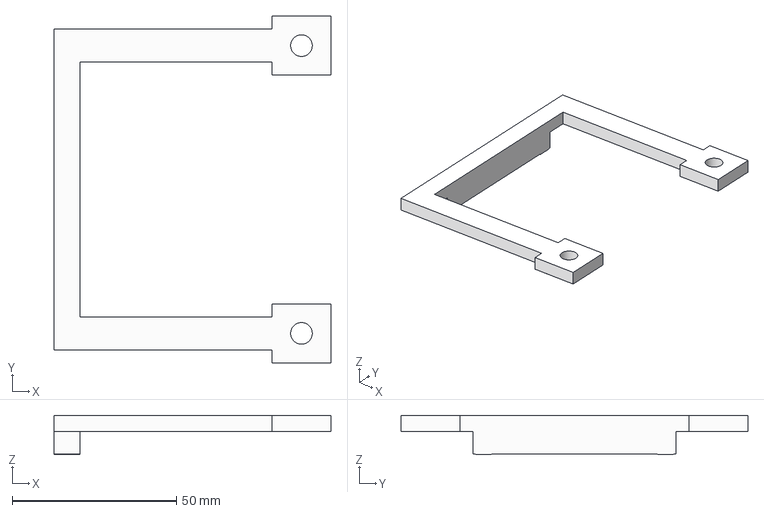
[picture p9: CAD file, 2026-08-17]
cad/exports/step/SEWCP-902_SADDLE.step
84.4 x 105.7 x 12.0 mm

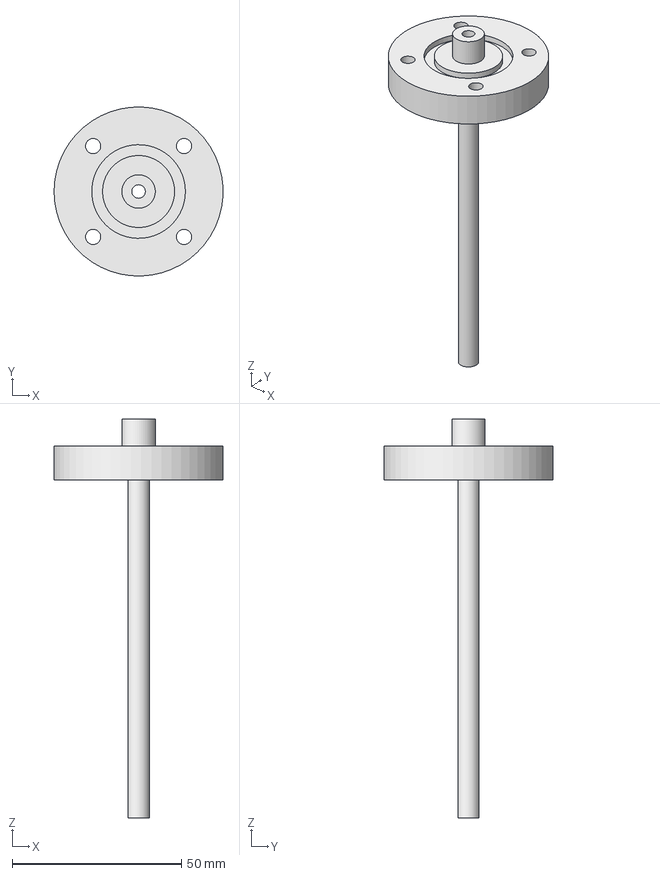
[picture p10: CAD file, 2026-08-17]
cad/exports/step/SEWCP-800_PORT_BODY.step
50.0 x 50.0 x 118.0 mm

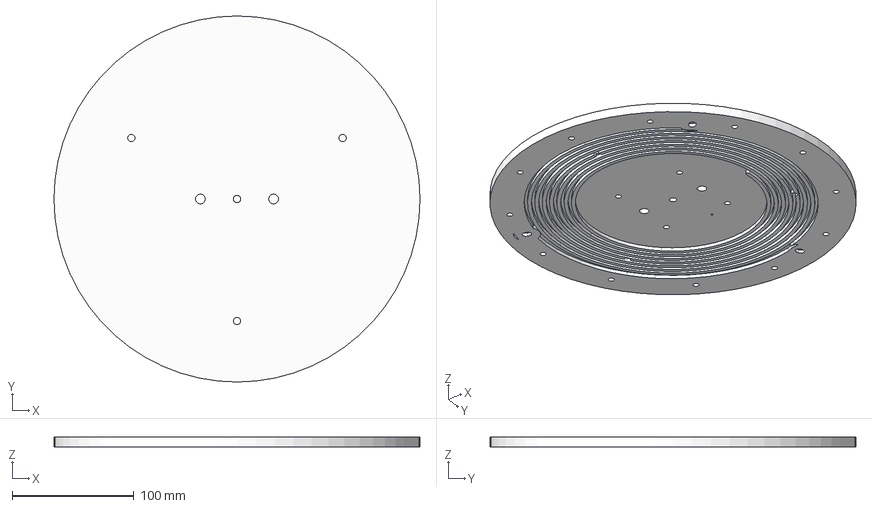
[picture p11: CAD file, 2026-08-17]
cad/exports/step/SEWCP-300_HEATER_PLATE.step
300.0 x 300.0 x 8.00 mm

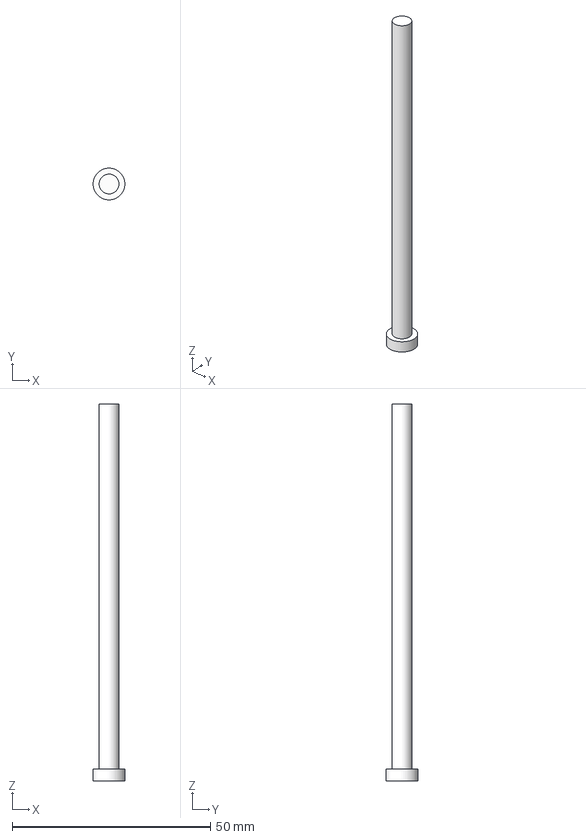
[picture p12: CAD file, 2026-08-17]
cad/exports/step/SEWCP-600_LIFT_PIN.step
7.99 x 8.00 x 95.0 mm

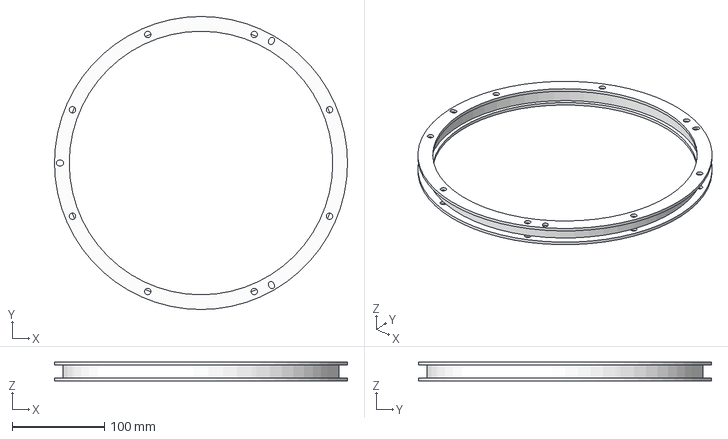
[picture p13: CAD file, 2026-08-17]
cad/exports/step/SEWCP-400_SUPPORT_RING.step
318.0 x 318.0 x 20.3 mm

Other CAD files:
cad/exports/stl/SEWCP-1000_RETAINER.stl
cad/exports/stl/SEWCP-200_COOLING_PLATE.stl
cad/exports/stl/SEWCP-300_HEATER_PLATE.stl
cad/exports/stl/SEWCP-400_SUPPORT_RING.stl
cad/exports/stl/SEWCP-500_ESC_PUCK.stl
cad/exports/stl/SEWCP-600_LIFT_PIN.stl
cad/exports/stl/SEWCP-700_ALIGNMENT_PIN.stl
cad/exports/stl/SEWCP-800_PORT_BODY.stl
cad/exports/stl/SEWCP-901_RF_STRAP.stl
cad/exports/stl/SEWCP-902_SADDLE.stl

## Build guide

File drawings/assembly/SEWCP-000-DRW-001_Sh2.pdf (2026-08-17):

DATUM A

## 20.000 (lapped, DR-3)

40.000

49.500

55.900

1.50 CHOKE GAP (SEWCP-301 ×16)

0.40 BOND LINE

WAFER PLANE 55.920 (MESA 0.020)

## INDENTURED BOM (SEWCP-000)

LVL | PART NO | NAME | QTY | MATERIAL | STATE
0 | SEWCP-000 | MASTER ASSEMBLY | 1 | — | Fusion assembly (c
1 | SEWCP-200 | COOLING PLATE | 1 | 6061-T6 | verified model (SE
1 | SEWCP-300 | HEATER PLATE | 1 | 6061-T6 | verified model (SE
1 | SEWCP-400 | SUPPORT RING | 1 | Al2O3 99.5% | verified model (SE
1 | SEWCP-500 | ESC PUCK | 1 | Al2O3 99.6% | verified model (SE
1 | SEWCP-600 | LIFT PIN | 3 | Al2O3 99.8% | verified model (SE
1 | SEWCP-700 | ALIGNMENT PIN | 6 | Ti-6Al-4V | verified model (SE
1 | SEWCP-800 | PORT BODY | 1 | 316L SST | verified model (SE
1 | SEWCP-901 | RF STRAP | 1 | C10100 OFHC | verified model (SE
1 | SEWCP-902 | SADDLE | 1 | 6061-T6 | verified model (SE
1 | SEWCP-1000 | RETAINER | 3 | 6061-T6 | verified model (SE
1 | SEWCP-301 | Thermal choke washer, Ti, 1.50 thk | 16 | Ti Grade 2 | spec-only
1 | SEWCP-401 | Support ring clamp ring | 1 | 316L | spec-only
1 | SEWCP-601 | Lift pin bushing, bore Ø5.60 +0.05 | 3 | Vespel/PEEK per | spec-only
1 | SEWCP-903 | RF terminal hardware set (4× M6×16 | 1 | A4-70 / Ag plate | spec-only
1 | SEWCP-904 | Deposition shroud | 1 | Ceramic per spec | spec-only
1 | HW-M640SHCS | M6 × 40 SHCS — Lower circuit: Base | 8 | A4-70 | spec-only
1 | HW-M616SHCS | M6 × 16 SHCS — Upper circuit: Supp | 8 | A4-70 | spec-only
1 | HW-M525SHCS | M5 × 25 SHCS — Cooling Plate ↔ Hea | 12 | A4-70 | spec-only
1 | HW-M525SHCS | M5 × 25 SHCS — Cooling Plate ↔ Hea | 4 | A4-70 | spec-only
1 | HW-M416SHCS | M4 × 16 SHCS — Vacuum Port flange | 4 | A4-70 | spec-only
1 | HW-M616SHCS | M6 × 16 SHCS — RF strap to Cooling | 2 | A4-70, silver-pl | spec-only
1 | HW-M620SHCS | M6 × 20 SHCS — RF bracket clamp to | 2 | A4-70 | spec-only
1 | HW-M412SHCS | M4 × 12 SHCS — Temp sensor bracket | 4 | A4-70 | spec-only
1 | SEWCP-100 | BASE PLATE (frozen reference) | REF | — | frozen — not part

## NOTES:

1. HEIGHTS ARE OBSERVED OCCURRENCE BOUNDS; NOMINAL AUTHORITY spec/00 §4.2.
2. FULL BOM: BOM/SEWCP-000_BOM_RevA.csv (CROSS-CHECKED 4 WAYS).
3. SEWCP-600 MATERIAL CORRECTED TO 99.8% ALUMINA (REPAIRS_S-2026-08-11-04).
TITLE SEWCP MASTER ASSEMBLY — Elevation + | NUMBER indentured BOM SEWCP-000-DRW-001 Sh 2 | REV A
MATERIAL — | FINISH — | SCALE 1:3 / 1:1.1
UNITS mm | DATE 2026-08-11 | ORIGIN AIEF autonomous run

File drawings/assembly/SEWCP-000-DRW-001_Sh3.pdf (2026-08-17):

## FASTENER SCHEDULE (spec/00 §9)

JOINT / FASTENER | QTY | GRADE | NOTES
M6 × 40 SHCS — Lower circuit: Base Plate ↔ Support Ring bottom fla | 8 | A4-70 | torque 6.0 N·m; Ø16 flat + Belleville stack
M6 × 16 SHCS — Upper circuit: Support Ring top flange ↔ Cooling Pl | 8 | A4-70 | torque 6.0 N·m; Ø16 flat + Belleville stack
M5 × 25 SHCS — Cooling Plate ↔ Heater Plate (outer choke) | 12 | A4-70 | torque 3.5 N·m; Ti washer + Belleville
M5 × 25 SHCS — Cooling Plate ↔ Heater Plate (inner choke) | 4 | A4-70 | torque 3.5 N·m; Ti washer + Belleville
M4 × 16 SHCS — Vacuum Port flange | 4 | A4-70 | torque 1.8 N·m; Flat
M6 × 16 SHCS — RF strap to Cooling Plate land | 2 | A4-70, silve | torque 6.0 N·m; Silver-plated flat + Belleville
M6 × 20 SHCS — RF bracket clamp to Base Plate | 2 | A4-70 | torque 6.0 N·m; Flat
M4 × 12 SHCS — Temp sensor bracket | 4 | A4-70 | torque 1.8 N·m; Flat

## NOTES:

1. SCHEDULE PARSED VERBATIM FROM spec/00 §9 — THE FROZEN AUTHORITY.
2. CERAMIC JOINT RULE: CERAMIC IN COMPRESSION ONLY; NO THREADS IN CERAMIC (spec/00 §9).
3. BELLEVILLE SELECTION PER spec/00 §9; RF HARDWARE SILVER-PLATED PER SEWCP-903.
4. ALIGNMENT LOCATORS ARE THEIR OWN FASTENER — 1.2 N·m (ECR-D-009, spec/06).
TITLE SEWCP MASTER ASSEMBLY — Fastener and torque schedule | NUMBER SEWCP-000-DRW-001 Sh 3 | REV A
MATERIAL — | FINISH — | SCALE 1:3 / 1:1.1
UNITS mm | DATE 2026-08-11 | ORIGIN AIEF autonomous run

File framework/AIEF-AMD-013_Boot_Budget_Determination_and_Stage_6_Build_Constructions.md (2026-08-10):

# AIEF-AMD-013 — Architecture Amendment: Boot-Budget Determination and Stage 6 Build Constructions

**Authority:** Chief Systems Engineer (A4) · **Instrument:** LAW-02 (disposition of a recorded blocker and of recorded open questions), LAW-01 + LAW-10 (change to a frozen artifact — `framework/framework.manifest.json`), LAW-12 (open decision with recorded rationale, never assumption; and reservation where the choice is not a determination)
**Scope:** (i) the determination of **CMP-BLOCK-006**, the V-09 token-budget breach that halts the first authoritative Stage 6 build; (ii) the five build open questions **OQ-B1 … OQ-B5** recorded in `project/STAGE-6_BUILD_OPEN_QUESTIONS.md`; (iii) the three lower-order items recorded at the foot of that file. **Nothing else.** No Stage 6 execution, no `core/MANIFEST.lock`, no distributable, no ledger write, no BINDING change, no tag, no commit.
**Date:** 2026-08-08 · **Session:** `S-2026-08-08-10`
**Amends:** `framework/framework.manifest.json` — nine changes, all inside `metadata.reproducible` and one `validation[V-09].verifies` extension, enumerated in `APR-012`
**Does not amend:** `AIEF-FRZ-001` (no byte, no digest, and — expressly — **no supersession in reading**: §1.8's derivation, its cap table and its 6,000 ceiling stand exactly as frozen) · `AIEF-AMD-001` … `AIEF-AMD-012` · either ADR · `SCH-framework-manifest.schema.json` (the amended manifest passes it unmodified) · `SCH-core-manifest.schema.json` or any emitted schema · any law rule or clause · any role contract · any partition, layer, tier, boot step, compiler stage or lifecycle definition · DC-1's normalisation of non-empty content, DC-2, DC-3, DC-4's coverage, grammar, order, preimage, self-exclusion, B2a procedure and worked example, DC-5 · TF-1 and TF-2 · **no `token_cap`, and not the 6,000 boot ceiling**
**Authorising basis:** live human-owner instruction of session `S-2026-08-08-10` (`core/PRECEDENCE.md` rank 1), directing that CMP-BLOCK-006 and OQ-B1…B5 be resolved according to the repository's authoritative records, that A4 independently inspect the V-09 failure and determine whether deterministic content reduction suffices or the frozen budget requires an architecture amendment, that no authoritative content be deleted, summarised, relocated or weakened, and that no assumption stand where the repository records an unresolved question. Recorded per LAW-10 in `project/approvals/APR-012` and `project/approvals/APR-013`

---

## Independence declaration

OQ-B1…OQ-B5 and the three lower-order items were raised by `software.software-engineer · S-2026-08-08-07` during the CMP-BLOCK-004 build and filed by `project-manager` action at rank-1 direction; the filing states expressly that **none may be ruled by the session that raised them**. CMP-BLOCK-006 was registered by `project-manager` action at the filing of VER-006, on the finding of `qa-engineer · S-2026-08-08-09b`, over evidence produced by `software.platform-engineer · S-2026-08-08-08` and certified by `software.test-engineer · S-2026-08-08-09`.

These rulings are made by `chief-systems-engineer · S-2026-08-08-10`, a cold session holding no state from any prior session and having authored none of the artifacts named above. Under AIEF-AMD-008 §AMD-20, agent identity for LAW-02, LAW-04 and LAW-05 independence is the pair (role, session): this session differs from `S-2026-08-08-07` **in both role and session**, and from every other contributing actor in at least session. The identity bar of the raising artifact is therefore satisfied, and it is confirmed here in writing as that artifact requires.

The same-authority ruled-and-applied departure is separately recorded in § *Separation of Duties*.

| Ruling | Subject | Change class |
|---|---|---|
| AMD-41 | CMP-BLOCK-006 — determination; content reduction insufficient; the remedy reserved to the human owner as **OQ-15** | Determination + reservation. **No manifest change** |
| AMD-42 | V-09's measured domain, the totals scope, and the measurement instant | Manifest change — two new `budget_measurement_record` members; `validation[V-09].verifies` extension |
| AMD-43 | OQ-B1 — lock JSON layout | Manifest change — `core_aggregate.lock_json_layout` |
| AMD-44 | OQ-B2 — `build_provenance` content | Manifest change — `metadata.reproducible.build_provenance_record` |
| AMD-45 | OQ-B3 — the lock self-measurement fixed point | Manifest change — `budget_measurement_record.lock_self_measurement` |
| AMD-46 | OQ-B4 — archive entry types and the directory-mode tension | Manifest change — `distributable.entry_types` |
| AMD-47 | OQ-B5 — the BINDING pin-line write form | Manifest change — `metadata.reproducible.binding_pin_write` |
| AMD-48 | DC-1 of empty content; AMD-33 run-fixed timestamp and build id | Manifest change — `per_artifact.empty_content`; `build_time_reproducibility.run_fixed_values` |

---

## AMD-41 — CMP-BLOCK-006: Determination, and the Remedy Reserved

**Disposes:** the *determination* required of A4 by CMP-BLOCK-006 (`project/OPEN_ITEMS.md`, Blocking) and by VER-006 §6a gate 1 · **Ruled by:** `chief-systems-engineer · S-2026-08-08-10` · **No manifest change**

### 1 · Independent re-measurement

The recorded breach was re-measured this session from the repository's own implemented families — `src/aief_stage6/tokenizers.py`, TF-1 `cl100k_base.tiktoken` and TF-2 `spiece.model`, assembled offline from the artifacts in `build/stage6/tokenizer_artifacts/`, artifact pins recomputed raw-octet and matching the trust-on-first-use record. Both pins reproduce: TF-1 `223921b76ee99bde995b7ff738513eef100fb51d18c93597a113bcffe865b2a7`, TF-2 `d60acb128cf7b7f2536e8f38a5b18a05535c9e14c7a355904270e15b0945ea86`. The full AMD-31 precondition run was executed with output redirected outside the repository; it reproduces V-01…V-08 and V-23…V-25 PASS and V-09 FAIL.

**Measured, this session, over the whole T0 ∪ T1 set** — capped and cap-null, present and absent:

| `files[]` path | Tier | Cap | TF-1 | TF-2 | Governing | Verdict |
|---|---|---|---|---|---|---|
| `BOOT.md` | T0 | 400 | 445 | **504** | 504 | **FAIL** |
| `FRAMEWORK.md` | T1 | 1100 | 652 | 748 | 748 | PASS |
| `core/MANIFEST.lock` | T1 | 200 | — | — | — | not on disk — emitted by Stage 6 |
| `core/PRECEDENCE.md` | T1 | 700 | 341 | 382 | 382 | PASS |
| `core/laws/INDEX.md` | T1 | 900 | 598 | 721 | 721 | PASS |
| `project/BINDING.md` | T1 | 800 | 483 | 574 | 574 | PASS |
| `project/STATE.md` | T1 | 1100 | 1503 | **1747** | 1747 | **FAIL** |
| `project/OPEN_ITEMS.md` | T1 | 600 | 6867 | **8673** | 8673 | **FAIL** |
| `core/workflows/WF-01_session.md` | T1 | null | 359 | 437 | 437 | not measured — cap-null |
| `project/ledger/HEAD` | T1 | null | 411 | 504 | 504 | not measured — cap-null |
| `adapters/INDEX.md` | T1 | null | 539 | 672 | 672 | not measured — cap-null |
| `core/profiles/mechanical/PROFILE.md` | T1 | null | 414 | 527 | 527 | not measured — cap-null |
| `core/profiles/mechanical/lifecycle/INDEX.md` | T1 | null | 398 | 530 | 530 | not measured — cap-null |
| `core/profiles/software/PROFILE.md` · `.../lifecycle/INDEX.md` · both `research` entries | T1 | null | — | — | — | not on disk — deliberately unemitted, AMD-011 §AMD-36 |
| **Measured totals** (capped set, per AMD-42) | | ceiling 6000 | **10889** | **13349** | **13349** | **FAIL** |

### 2 · The recorded values do not reproduce — a finding of the first order

`OPEN_ITEMS.md` records the breach as `BOOT.md` 504, `STATE.md` **1791**, `OPEN_ITEMS.md` **7937**, aggregate **12657** (TF-2) / **10296** (TF-1); TCR-001 §3.2 and VER-006 C4 independently confirmed those figures to the digit, and this session confirms that they agreed with each other and with the platform engineer's diagnostic exactly.

**Five of the eight measured values still reproduce to the digit** — `BOOT.md` 445/504, `FRAMEWORK.md` 652/748, `core/PRECEDENCE.md` 341/382, `core/laws/INDEX.md` 598/721, `project/BINDING.md` 483/574. **Three do not:** `project/STATE.md` 1516/1791 → 1503/1747; `project/OPEN_ITEMS.md` 6261/7937 → 6867/8673; totals 10296/12657 → 10889/13349.

Nothing in the compiler, the tokenizers, the pinned artifacts or the manifest's measurement rules changed between the two measurements. What changed is the content of two `partition: project`, `mutability: mutable`, `lifecycle: instance-created` files, written after the measurement by the sessions that recorded the measurement's own result. The largest single contributor is demonstrable: removing the `CMP-BLOCK-006` row and the `OI-V-09` row — the two rows VER-006's FIND-Q6-1 disposition added — returns `OPEN_ITEMS.md` from 6867/8673 to 6450/8149, the two rows costing 199/233 and 218/291 respectively.

> **The act of recording the budget breach in the authoritative register made the budget breach larger.** That is not a defect of any actor. It is a property of the construction: V-09 is a build gate whose measured domain includes registers that grow when the gate fails.

Both prior measurements were honest and correct at their instant. The disagreement is not a defect in TCR-001 or VER-006; it is evidence about the construction, and it is declared as a recorded property by AMD-42 (`measurement_instant`) so that no future re-measurement mistakes drift for tampering.

### 3 · The membership of the measured set, and who may lawfully change what

The T0 ∪ T1 set has **seventeen** `files[]` members; **eight** carry a non-null `token_cap` and are the measured set (AMD-42); nine are cap-null and are not measured; four of those nine are not on disk by ruling. The measured set partitions by write access, and this is decisive:

| Measured file | Partition | Write access | Mutability | Who may lawfully change its bytes |
|---|---|---|---|---|
| `BOOT.md` | `root` | **framework-only** | immutable | The compiler, by Stage 1 re-emission — **not this session, not any agent, not by hand** |
| `FRAMEWORK.md` | `root` | **framework-only** | immutable | as above |
| `core/PRECEDENCE.md`, `core/laws/INDEX.md` | `core` | **framework-only** | immutable | as above |
| `core/MANIFEST.lock` | `core` | **framework-only** | immutable | Stage 6 only |
| `project/BINDING.md` | `project` | agents-and-humans | mutable | `project-manager` |
| `project/STATE.md` | `project` | agents-and-humans | mutable | `chief-systems-engineer` |
| `project/OPEN_ITEMS.md` | `project` | agents-and-humans | mutable | `project-manager` |

### 4 · The determination

> **Deterministic content reduction is not sufficient, and cannot be made sufficient by any actor available today. CMP-BLOCK-006 requires an amendment to the frozen budget construction. The breach is two distinct defects reported by one check, and they have different cures.**

**Defect class A — a compiler-output cap the compiler's own output cannot meet.** `BOOT.md` governing 504 > cap 400. `BOOT.md` is `framework-only` write access and `mutability: immutable`; no agent may hand-edit it, and changing it is a Stage 1 re-emission, which is CMP-BLOCK-004 — the full compiler that does not exist. A disposition of the form *"reduce `BOOT.md`"* therefore makes Stage 6 unreachable until the whole six-stage compiler is built, which directly contradicts AMD-25's ruling that a Stage-6-only increment is admissible for Stage 6. That reading is not available.

Nor is the cap reachable by rendering. `BOOT.md`'s content is a Stage 1 render of the eleven frozen `boot_sequence` steps plus the frozen tier rule and governing rule. Measured this session under the governing family: the eleven-row boot table alone is **346** TF-2; the tier rule is **47**; the governing rule is **82** — a floor of **475 > 400** for a document that renders only what the frozen architecture declares. Deleting the `Cost` column, which MI-11 requires every boot step to declare, still leaves **436 > 400**. **The 400 cap is unachievable against `BOOT.md`'s own frozen specification.** That is precisely the ground on which `AIEF-FRZ-001` §1.8 itself superseded the Rev A ceiling of 3,900 — *"it was asserted without derivation and was unachievable against its own file specifications."* The defect is in the cap, not in the file. Its cure is a cap amendment.

**Defect class B — a fixed cap on live, monotonically growing project state.** `project/STATE.md` 1747 > 1100 and `project/OPEN_ITEMS.md` 8673 > 600; together they contribute **10,420** of the 13,349 governing total. These are `mutability: mutable`, `lifecycle: instance-created`, `integrity: unhashed` files: the compiler emits their initial instance and every session thereafter writes them under LAW-09, which makes a session *"a transaction [that] reads state at start and writes state at close."* Two consequences follow directly:

1. **The cap is not a constraint the build can satisfy.** DC-4 refuses to cover these files — *"unhashed partitions (project, adapters) are never covered"* — and `FROZEN.md` refuses to register them — *"`project/`, `adapters/` — nothing; mutable by design."* The build would be halted on the state of files that no integrity mechanism of the build binds, and that the build cannot change.
2. **`project/OPEN_ITEMS.md` is authoritative** — *"This register is authoritative; `STATE.md` is a derived cache and `ENGINEERING.md` is an index."* It stands at 8,673 governing tokens against a 600 cap: a factor of **14.5**. Measured this session, a hypothetical register reduced to nothing but its forty-one identifiers and the single word `open` per row already costs **454** TF-2 — 76% of the cap, carrying no item text, no blocking status and no authority, and admitting perhaps a dozen more entries before the bare index itself breaches. Any reduction that brings the real register under 600 destroys or relocates the recorded blockers, findings, dispositions and residuals. Under the directing instruction and under LAW-06, that is a defect, not a fix.

> **A fixed 600-token cap on an authoritative register that grows monotonically with the project's engineering history is itself an architecture defect.** It is not a cap the register can be held to, because the register's size is a function of how much has been recorded, and recording is the register's purpose.

**Content reduction, applied where it is lawful and lossless, does not close the gap.** `project/STATE.md` is the one measured file this session both owns (`owner_role: chief-systems-engineer`) and may reduce without loss, because the file declares itself *"a derived cache."* That reduction was performed and is recorded in § *Content Reduction Performed* below. Even with `STATE.md` inside its cap, the aggregate remains far above 6,000 and `BOOT.md` and `OPEN_ITEMS.md` remain in breach. **This is the demonstration, not the remedy.**

### 5 · What is *not* determined, and why

The determination above fixes that an amendment is required and rules out the two pure strategies:

| Strategy | Judgement |
|---|---|
| Content reduction alone | **Ruled out, determinately.** `BOOT.md` cannot be reduced by any available actor and cannot meet 400 by any conforming render; `OPEN_ITEMS.md` cannot be reduced to 600 without destroying authoritative content |
| Cap and ceiling raise alone | **Ruled out, determinately.** Caps sufficient for the measured values would sum past 13,000, breaching **MI-4** (Σ `token_cap` over T0 ∪ T1 ≤ 6,000) and forcing the ceiling past 40% of the 32,000-token portability floor, destroying the `AIEF-FRZ-001` §1.8 derivation (32,000 × 20%). And because `OPEN_ITEMS.md` grows monotonically, any cap set this way is re-breached by the next session — a cap that must be amended at every session close is not a cap |

What remains is a genuine choice among lawful architecture alternatives with real trade-offs. It is **not** a determination, and under LAW-12 this authority does not make it. Following exactly the precedent of AIEF-AMD-010 §AMD-34, which recorded the OQ-13 options and reserved the choice, the options are recorded and the choice is **reserved to the human owner as OQ-15**.

### 6 · The admissible options — recorded for the owner

The MI-4 arithmetic that binds every option: Σ `token_cap` over T0 ∪ T1 is **5,800** today against a limit of **6,000**, so **200 tokens of cap headroom exist in total** and every raise draws on the same pool.

| Option | Mechanism | Properties |
|---|---|---|
| **(a) Split the authoritative register: bounded T1 index, unbounded body** | Add a `files[]` entry for the full register (e.g. `project/OPEN_ITEMS_REGISTER.md`, tier T4, cap null, partition `project`, generator 3); `project/OPEN_ITEMS.md` becomes a bounded index carrying every identifier, its class and status, and a pointer. Boot step B7 is unchanged — it still reads `project/OPEN_ITEMS.md`. Manifest change; a Stage 3 emission question for the new artifact | **Preserves every authoritative byte** at a declared home, with a 1:1 mapping. It is what the tier architecture is *for* — *"Loading everything is the default failure. Tiers bound the cost of becoming oriented."* Cost: the register is no longer wholly loaded at boot, so a booting session sees the index and must load the body on cause; and the bare index measured at 454 today still leaves only ~150 tokens of growth against the 600 cap, so the index's own cap likely needs raising too (drawing on the 200-token pool) or its row grammar constraining |
| **(b) Re-derive the budget from a current portability floor** | Amend `version.min_context_window` upward from 32,000, re-derive the 6,000 ceiling at the frozen 20% share, and redistribute all eight caps. Manifest change; `AIEF-FRZ-001` §1.8's derivation table superseded in reading, bytes unchanged | Honest and simple, and it is the only option that also cures `BOOT.md` without a re-render. Cost: it raises the declared **portability floor** — the framework then refuses to claim support for a 32,000-token host — which is a product decision, not an engineering one; and it does not stop `OPEN_ITEMS.md` growing past whatever new cap is set |
| **(c) Narrow V-09's build-time domain to the compiler's own output** | Rule that the V-09 *precondition* measures the integrity-hashed, framework-emitted T0 ∪ T1 files (the build's own product), and that the `project`-partition tier caps are enforced at **session close** under LAW-09 tier discipline instead of at build time. Manifest change; a new or extended check | Aligns the build gate with what the build controls and with DC-4's own coverage rule, and makes the measurement reproducible from the build's declared inputs. Cost: **it does not fix the live overrun** — `OPEN_ITEMS.md` at 8,673 tokens genuinely does blow a 6,000-token boot ceiling on a 32,000-token host today — so taken alone it moves the failure out of the build's view without curing it. Admissible only in combination with (a) or (b) |
| **(d) Combination** | Any consistent combination of the above, with `BOOT.md`'s cap raised to at least its measured governing value | The only combinations that close both defect classes are {(a) or (b)} + a `BOOT.md` cap cure; (c) may be added to either |

**`BOOT.md`'s cap, separately.** Raising it alone from 400 to 550 would give Σ = 5,950 ≤ 6,000 and satisfy MI-4 today. This authority declines to rule it in isolation: that raise consumes three quarters of the entire cap headroom, and the headroom is the same pool option (a) needs for the index cap and option (b) redistributes wholesale. Allocating it before the register question is decided would prejudice the owner's choice. The *determination* — that 400 is unachievable and a cap amendment is the cure — stands; the *value* travels with OQ-15.

### 7 · A4 recommendation — recommendation, not decision

**Option (a), combined with a `BOOT.md` cap raise and, if the owner wishes, (c).** Grounds, in order:

1. It is the only option that both preserves every authoritative byte and holds the boot ceiling at its frozen, derived value. Neither the ceiling nor the register's authority has to give way.
2. It uses a mechanism the architecture already declares and already relies on. Tiering the register is the same move the framework makes for the ledger — `HEAD` gives O(1) lookup at B4 and *"body never read at boot"*, with sealed segments T4-only (OD-9). The register is the one authoritative artifact for which that pattern was never applied.
3. It is self-correcting under growth in a way (b) is not: the index grammar bounds per-entry cost, so the register may grow without end while the boot cost stays flat. (b) buys a fixed amount of room once.
4. It does not touch the portability floor, which is a claim to users rather than an internal parameter.

Option (b) is entirely lawful and is the simplest thing that could work; it is ranked below (a) only because it trades a user-facing claim for internal room and does not bound future growth. Option (c) alone is recommended **against**, for the reason stated in the table: it would make the build stop reporting a real operational overrun without curing it, which is the FM-3 pattern `AIEF-FRZ-001` §1.7 exists to prevent.

> **Recorded explicitly: the CHOICE among (a), (b), (c) and their combinations, and the resulting cap values, is the human owner's** (`project/BINDING.md` `approval_authority: human-owner`; every cap and ceiling is frozen architecture, and §1.8's derivation is a ratified product parameter). **OQ-15 is open** until the owner decides. **CMP-BLOCK-006 remains BLOCKING**: until it is disposed, the AMD-31 gate fails, and no conforming `core/MANIFEST.lock` can lawfully exist.

### 8 · What this ruling deliberately does not do

- It does **not** delete, summarise, relocate or weaken any authoritative content. `project/OPEN_ITEMS.md` is not reduced by a single recorded item; every entry it carried before this session it carries after, and this session adds to it.
- It does **not** change any `token_cap` or the 6,000 ceiling, and it supersedes no phrase of `AIEF-FRZ-001` in reading. §1.8 stands as frozen.
- It does **not** narrow V-09's measured set. AMD-42 declares the reading already in force and closes a recorded ambiguity; it excludes nothing that was previously included.
- It does **not** authorise Stage 6, create `core/MANIFEST.lock`, or touch `project/BINDING.md`.

---

## AMD-42 — V-09's Measured Domain, Totals Scope and Measurement Instant

**Disposes:** the recorded lower-order item *"budget totals scope read as capped T0∪T1 files only (cap-null T1 files excluded) — confirm intent"* · **Ruled by:** `chief-systems-engineer · S-2026-08-08-10`

### Question, restated

`budget_measurement_record.content` clause 1 names *"every file carrying a non-null `token_cap` in tiers T0 and T1"*; clause 2 names *"per-family T0 plus T1 totals"* without repeating the qualifier. The implementation reads clause 2 as the total over clause 1's set and disclosed the reading as an open question. Nine T0 ∪ T1 entries carry `token_cap: null`; five of them exist on disk and measure 2,670 TF-2 in total, so the reading is not academic.

### Ruling

> **The measured set is exactly the `files[]` entries whose tier is T0 or T1 and whose `token_cap` is non-null. The per-family totals of clause 2 are the totals over exactly that set. Cap-null tier entries are outside the record. The interim reading is confirmed.**

Grounds, each evaluable from declared text:

1. **It is MI-4's own domain.** MI-4 is *"Σ `token_cap` over T0 ∪ T1 ≤ 6,000"* — a sum over exactly the entries that declare a cap. The measurement side of a budget and the declaration side of the same budget must range over the same set, or the invariant that makes the budget *"close by construction"* is checking a different thing from the check.
2. **It is `AIEF-FRZ-001` §1.8's own arithmetic.** The frozen derivation table lists eight files, sums them to **5,800**, and records **200** of headroom against the 6,000 ceiling. That Sum row is computed over exactly the capped set. Reading the aggregate over all T0 ∪ T1 would make the frozen table's own headroom figure false the moment any cap-null tier file exists — and nine do.
3. **A cap-null entry declares no bound.** There is nothing for a verdict to compare against, and `verdict_rule` speaks only of *"any per-file cap breach or aggregate ceiling breach"*. Admitting unmeasurable files into an aggregate that is compared to a ceiling derived from the sum of caps would compare two different quantities.

### Recorded residual — expressly not closed

Boot demonstrably reads a cap-null file. `boot_sequence[B4].files` names `ledger-head`, and `project/ledger/HEAD` carries `tier: T1`, `token_cap: null`, and measures **411 / 504** today. The boot-loaded set is therefore the eight measured files **plus** `project/ledger/HEAD`; the remaining eight T1 entries are read at no boot step at all. So the measured set under-covers the real boot cost by exactly one file, and over-covers nothing.

This is a genuine exposure and it is **not** cured here: assigning `ledger-head` a cap draws on the same 200-token MI-4 headroom that AMD-41 §6 reserves to OQ-15, and would prejudge it. Recorded as **OI-C-08**, owner A4 with OQ-15, and named in the manifest text so the gap is self-announcing rather than inferred.

### Ruling — the measurement instant

> **The budget record is a measurement of the tree at the instant of the build. It is not a property of the manifest and is not a reproducible constant. A later re-measurement that disagrees with a recorded one is expected drift, not a measurement defect.**

This makes the AMD-41 §2 finding a declared property rather than a discovery waiting to be re-made. It changes no verdict: `verdict_rule` still halts the build on any breach at the instant measured.

### Manifest change

`metadata.reproducible.budget_measurement_record` — two new members, `measurement_domain` and `measurement_instant`; `authority` extended. `validation[V-09].verifies` extended to bind the check to the declared domain — the AMD-19/AMD-26 lesson, *a ruling without a check is a convention*. No schema amendment.

---

## AMD-43 — OQ-B1: Lock JSON Layout

**Disposes:** OQ-B1 · **Interim choice in force:** 2-space indent, LF, one terminal LF, `ensure_ascii` false · **Ruled by:** `chief-systems-engineer · S-2026-08-08-10`

### Ruling

> **The interim choice is adopted as normative and made complete.** `core/MANIFEST.lock` is serialised with two-space indentation per nesting level, LF line endings, exactly one terminal LF, no trailing whitespace on any line, no space before a name separator and exactly one space after it, one member or array element per line, and no escaping beyond what RFC 8259 requires — a non-ASCII character is emitted as itself, never as a `\uXXXX` escape. Declared member order is emission order and is never sorted.

Grounds: the lock is a T1 file bearing a 200-token cap **and** a byte-identity requirement across at least two executions and, at V-10, two platforms. A layout left to the implementation is a layout that may differ between two conforming implementations, which would make `build_time_reproducibility` and V-10 tests of one implementation rather than of the build. Layout is therefore part of the specification. Adopting the interim choice — rather than a different one — is deliberate: it is already implemented, already certified against (TCR-001 C6), and no ground was found to prefer any alternative, so changing it would churn the first integrity baseline for no gain.

The escaping clause is load-bearing: `ensure_ascii` true and false produce different octets for the same JSON value, so leaving it undeclared leaves byte-identity undeclared. Rejected: minified single-line JSON (unreadable at B2a's digest read, and no smaller in tokens where it matters); sorted keys (contradicts the declared member order of `lock_serialisation`, which exists to keep `aggregate_digest` ahead of `files`).

### Manifest change

`metadata.reproducible.digest_constructions.core_aggregate.lock_json_layout` — new member, beside the `lock_serialisation` member it completes. No schema amendment.

---

## AMD-44 — OQ-B2: `build_provenance` Content

**Disposes:** OQ-B2 · **Interim choice in force:** source manifest DC-1, selected profile, stage, build id, run-fixed timestamp · **Ruled by:** `chief-systems-engineer · S-2026-08-08-10`

### Gap, restated

`build_provenance` is a **required** field of `sch-core-manifest`, and no text anywhere declared its content. A required field with undeclared content is the same defect class AMD-27 and AMD-29 closed for the digests: required, verified, never constructed.

### Ruling

> **`build_provenance` carries exactly six members, in this order: `source_manifest`, `source_manifest_dc1`, `selected_profile`, `compiler_stage`, `build_id`, `timestamp`.** The interim choice is adopted and closed, with `source_manifest` made explicit alongside its digest.

| Member | Value | Why it belongs |
|---|---|---|
| `source_manifest` | `framework/framework.manifest.json` | Names the input; the path is fixed but stating it makes the record self-describing |
| `source_manifest_dc1` | DC-1 of that manifest, 64 lowercase hex | **The load-bearing member.** It binds the lock to the manifest revision it was built from — the manifest is the single source of truth, and without this the lock records an aggregate whose coverage definition is unrecoverable |
| `selected_profile` | `BINDING.active_profile` at build time | With `files[]` and `enabled_agents`, this determines the covered set (AMD-27, AMD-39). A lock whose coverage input is unrecorded cannot be audited |
| `compiler_stage` | `6` | The emitting stage, per AIEF-AMD-007's rule that stage is declared, never inferred |
| `build_id`, `timestamp` | the run-fixed pair of AMD-48 | The provenance of the release run; the only two members not derived from files |

> **The set is closed.** Every value is a function of the manifest, of `project/BINDING.md`, or of the run-fixed pair. **Host name, user name, working directory, tool or interpreter versions, per-execution wall-clock time and any environment capture are prohibited** — each varies across the executions and platforms that `build_time_reproducibility` and V-10 require to agree octet for octet, so admitting any of them would make byte-identity unreachable by construction. The conventional build-provenance habit of capturing the environment is exactly wrong here.

Recorded, unchanged: `build_provenance` is one of the lock members the BINDING pin does not bind (AMD-27 *recorded_residual*). Tamper on it is detected by V-12 and version control, not by B2a.

### Manifest change

`metadata.reproducible.build_provenance_record` — new object. No schema amendment: `sch-core-manifest` requires the field and constrains no property of it.

---

## AMD-45 — OQ-B3: The Lock Self-Measurement Fixed Point

**Disposes:** OQ-B3 · **Interim choice in force:** lock row marked DEFERRED; emitted lock cap-checked post-serialisation, breach halts · **Ruled by:** `chief-systems-engineer · S-2026-08-08-10`

### Gap, restated

`files[manifest-lock]` carries `token_cap: 200`, so the lock is inside the measured set (AMD-42). But the budget record lives inside the lock, so the lock's own count inside its own record is a fixed point: writing the count changes the text whose count was written. No declared text resolves it.

### Ruling

> **The lock's per-file row is emitted with null counts, a null governing value and verdict `DEFERRED-SELF-MEASURED`, and contributes nothing to the per-family totals. The serialised lock octets are then measured under both families against the 200 cap after serialisation and before the archive is built; a breach halts the build exactly as an in-record breach does.** The deferral is keyed on the path `core/MANIFEST.lock` and on nothing else.

The interim behaviour is adopted with **one substantive correction**. The implementation defers on *absence from the tree* rather than on identity — the condition TCR-001 recorded as finding F1: *"the deferral is keyed on absence, not on identity. If a second capped file were ever absent it would defer rather than fail."* That is a latent fail-open: a measured file deleted from the tree would be silently deferred instead of halting the build. **Keying the deferral on the path closes it**, and the rule states expressly that any other measured file absent from the tree is a build defect that must halt. This disposes TCR-001 F1.

Why the cap is not simply dropped from the lock, and why the fixed point is not iterated:

| Alternative | Why rejected |
|---|---|
| Remove `token_cap` from `files[manifest-lock]` | The 200-token cap is frozen at `AIEF-FRZ-001` §1.8's table, and B2a's *"digest read"* is the reason `lock_serialisation` puts `aggregate_digest` before `files`. Dropping the cap would thaw frozen text and discard the constraint that shapes the lock's member order |
| Iterate to a fixed point (write count, re-measure, re-write until stable) | May not converge, and where it does the converged value depends on the iteration order — a construction whose output depends on how it was computed is not a construction. It also makes the lock's bytes a function of a search, defeating byte-identity |
| Record a placeholder digit inside the record | AMD-27 rejected alternative C in the same terms: a placeholder is the *required-but-never-constructed* defect class, and the value would be unverifiable by the construction containing it |

Post-serialisation measurement has the property the others lack: it is a **single-pass, terminating check on the final octets** — the very octets a booting session reads at B2a — and it enforces the cap fully. The record honestly says the row was deferred rather than asserting a number it cannot know.

### Manifest change

`metadata.reproducible.budget_measurement_record.lock_self_measurement` — new member. No schema amendment.

---

## AMD-46 — OQ-B4: Archive Entry Types

**Disposes:** OQ-B4 · **Interim choice in force:** file-only tar entries; directory-mode rule treated as vacuous · **Ruled by:** `chief-systems-engineer · S-2026-08-08-10`

### Tension, restated

`distributable.contents` says the archive holds the DC-4 covered set plus the lock and *"nothing else"*; `distributable.determinism` declares *"mode 0644 for regular files and 0755 for directories"*, which appears to contemplate directory entries the contents clause excludes.

### Ruling

> **Regular file entries only.** The archive carries one entry per member of `contents` and no directory entry, no symbolic link, no hard link and no device entry; an extractor creates directories from the entry paths. **The `contents` clause governs; the directory-mode clause is vacuous for a conforming archive** — it constrains any directory entry a future ruling might require, and is never a licence to add one.

There is no real conflict to resolve. `contents` is an enumeration of members and `determinism` is a table of header field values; an enumeration that says *"nothing else"* is not overridden by a mode value stated for an entry type the enumeration does not admit. Reading it the other way would add entries to the archive that DC-4 does not cover and `contents` excludes — and every added entry is an octet in the archive that DC-5 binds, so the reading is not cosmetic.

The vacuous clause is retained rather than deleted: deleting it would remove the declared mode for any future entry type, and re-deriving it later is exactly the kind of undeclared-value defect this amendment series exists to prevent.

### Manifest change

`metadata.reproducible.distributable.entry_types` — new member. No schema amendment.

---

## AMD-47 — OQ-B5: The BINDING Pin-Line Write Form

**Disposes:** OQ-B5 · **Interim choice in force:** value-token-only replacement · **Ruled by:** `chief-systems-engineer · S-2026-08-08-10`

### Ruling

> **Exactly one line of `project/BINDING.md` matches `core_digest_pin` followed by a colon. The build replaces the value token on that line with the 64-lowercase-hexadecimal DC-4 `aggregate_digest` and preserves every other octet of the file** — the leading indentation, the whitespace run between the colon and the value, any inline comment following the value, that line ending, and every other line unchanged. **Zero matching lines, more than one matching line, or a candidate pin value that is not 64 lowercase hexadecimal characters halts the build.**

Grounds: `generation_order[6].outputs` already classifies this output as *"a field write into an already-emitted instance artifact, **not** a re-emission of the project partition"*. A write that also realigned the line or dropped its inline comment would make the diff of an integrity-critical field larger than the field itself, and would put the compiler in the business of formatting an artifact in a partition it does not own — `project` is `agents-and-humans` write access and `never-touched` on upgrade. Preserving the inline comment matters concretely: `BINDING.md` today carries `core_digest_pin: PENDING-STAGE-6   # emitted by Compiler Stage 6`, and that comment is the human-readable record of which stage owns the field.

The three halt conditions are stated so the writer is a total function: a pin line that is absent, duplicated, or receiving a malformed value are all states in which the correct behaviour is to stop, not to guess.

### Manifest change

`metadata.reproducible.binding_pin_write` — new object. No schema amendment.

---

## AMD-48 — DC-1 of Empty Content; the Run-Fixed Timestamp and Build Id

**Disposes:** the two remaining lower-order items recorded at the foot of `project/STAGE-6_BUILD_OPEN_QUESTIONS.md` · **Ruled by:** `chief-systems-engineer · S-2026-08-08-10`

### Ruling — DC-1 of a zero-length file

> **A file whose normalised content is empty — no line survives the trailing-blank-line removal — has the empty octet string as its DC-1 preimage. Its DC-1 digest is therefore `e3b0c44298fc1c149afbf4c8996fb92427ae41e4649b934ca495991b7852b855`, the SHA-256 of zero octets.**

DC-1's *"append exactly one terminal LF"* step applies to surviving content, not to emptiness. Appending an LF to nothing would give an empty file and a file holding one blank line the same digest, collapsing two distinct states into one — and a construction that cannot distinguish two files it is asked to distinguish is a weaker construction for no benefit. The chosen reading is also already consistent with DC-2's declared `empty_registry` value, which is the SHA-256 of the empty preimage under the same reasoning; one framework, one treatment of emptiness.

**No non-empty digest changes.** Every digest recorded anywhere in this repository is unaffected: the rule defines a case that was undefined, and no covered or registered artifact is empty today. Stated expressly: **this defines the digest of an empty file; it does not licence one.** An emitted or registered artifact with no content remains a defect under the zero-dead-file rule of `AIEF-FRZ-001` §1.5.

### Ruling — AMD-33 run-fixed values

> **The Stage 6 build identifier and the measurement timestamp are captured once per release run, before its first execution, and are supplied unchanged to every execution of that run. They are inputs to the executions and never outputs of them.**

AMD-33 requires *"every execution [to yield] a byte-identical distributable"*. `build_provenance` and the budget record both carry a timestamp and a build id. A timestamp taken per execution would place a differing octet in every lock, hence in every archive, hence in every DC-5 — making byte-identity unreachable by construction and turning AMD-33's halt into a permanent one. Capturing them once per run is therefore not an implementation convenience; it is the only reading under which AMD-33 is satisfiable at all.

It follows that **the release run, not any single execution, is the unit of provenance** — which is precisely why those two values, and no other environment fact, are admitted to `build_provenance` (AMD-44). The rule applies equally to V-10's two-platform executions, where the same pair is carried across platforms.

### Manifest change

`metadata.reproducible.digest_constructions.per_artifact.empty_content` — new member, with the `status` member extended to point at it; `metadata.reproducible.build_time_reproducibility.run_fixed_values` — new member, with `authority` extended. No schema amendment.

---

## Content Reduction Performed

One reduction was performed, on the one measured file this session both owns and may reduce without loss. It is recorded here in full, per the directing instruction.

| | |
|---|---|
| File | `project/STATE.md` (`owner_role: chief-systems-engineer`; `mutability: mutable`; partition `project`) |
| Authority to reduce | The file's own declaration: *"This register is authoritative; **`STATE.md` is a derived cache**"* (`project/OPEN_ITEMS.md`). Nothing is recorded in `STATE.md` alone |
| Constraint honoured | `tpl-current-state` required sections all retained: Lifecycle stage, Active gate, Compiler stage, Last ledger sequence, Open blockers, Active tasks, Frozen set hash, Next action |
| Method | Narrative prose that restated content held authoritatively elsewhere was replaced by a pointer to its authoritative home. No blocker, open item, digest, count or lineage value was dropped |

The before-and-after measurement is recorded in `APR-012` § *The reduction performed*, and not here: a file inside the freeze registry cannot carry a number that a later measurement of a mutable file would falsify, and a file inside the measured set cannot state its own post-reduction count without changing it. `project/STATE.md` § *Budget* carries the standing verdict and points at `APR-012`.

**The reduction does not close the breach**, and it is not offered as a remedy: `BOOT.md` and `project/OPEN_ITEMS.md` remain in breach and the aggregate remains far above 6,000. It is the demonstration that supports AMD-41 §4 — the one lawful, lossless reduction available to this session, performed in full, and still insufficient.

**No reduction of `project/OPEN_ITEMS.md` was performed, deliberately.** It is the authoritative register; no reduction of it to 600 tokens is possible without destroying or relocating recorded content, and the relocation option is reserved to the owner as OQ-15 option (a). This session **added** to that register and reduced nothing in it.

---

## Blast Radius

Determined by inspecting what renders each changed manifest section, following the AMD-008/AMD-009/AMD-012 method.

| Changed section | Rendered by | Effect |
|---|---|---|
| `metadata.reproducible.*` — seven additive members, two `authority`/`status` extensions | `.ai/FRAMEWORK.md` § Integrity renders DC-1's headline rule only, unchanged | **None** |
| `validation[V-09].verifies` | `core/validation/CHECKS.md` and `core/validation/MANIFEST` — Stage 5 output emitted at `S-2026-08-08-03` | **Already stale in this exact field** (OI-V-07, from AMD-010). This extension deepens the existing staleness; it creates no new stale artifact and no new open item. Check count unchanged at 25. Re-emission is Stage 5 compiler work under CMP-BLOCK-004 |
| `adapters/ADP-ci.md` | Already stale (OI-C-02); check count unchanged | **No new staleness** |
| `src/aief_stage6/**` | Not rendered from the manifest; it *implements* it | **Implementation delta owed**, recorded as OI-C-09: one substantive change (AMD-45 — key the lock deferral on the path, not on absence; TCR-001 F1) plus conformance re-certification of the layout, provenance and pin-write rules against their now-normative texts. `src/` is PR-controlled; **not performed here** — A4 does not implement what it ruled (SOD-1) |
| `tests/**` | Not rendered from the manifest; it *asserts against* it | **Three assertions are now stale**, observed on a full-suite run at this session's close (114 tests: 111 pass, 3 fail; **no implementation defect**). `test_stage6_certification_evidence.py::TestV09Recomputation` pins the S-08 measurement of two `mutable` project files as constants — `project/STATE.md` 1791 and the totals 10296 / 12657 — which AMD-42 `measurement_instant` declares are not constants; `test_stage6_coverage_and_build.py::test_v24_live_registry` pins the registry at 28 members while V-24 itself **passes** at 29. Each failure is the ruling and the registry working, asserted against by a snapshot. Folded into OI-C-09; test maintenance belongs with the re-certification and is **not performed here** |

| Artifact | Change | Method |
|---|---|---|
| `framework/framework.manifest.json` | The nine changes of AMD-42…AMD-48 | Surgical edit under `APR-012`; re-registered in `FROZEN.md` at the new DC-1 |
| `framework/AIEF-AMD-013_…` | **NEW** — this instrument | Registered in `FROZEN.md` under `APR-013` (AMD-21 criterion) |
| `project/FROZEN.md` | Manifest row re-registered; this instrument added, 28 → 29; aggregate recomputed under DC-2 | Registry edit under `APR-012`/`APR-013` |
| `project/OPEN_ITEMS.md` | CMP-BLOCK-006 disposition status; OQ-B1…B5 closed; OQ-15, OI-C-08, OI-C-09 opened; TCR-001 F1 disposed under OI-V-09 | Register edit — **additive only** |
| `project/STATE.md` | `frozen_set_hash`; blockers; open items; `next_action`; § Budget; the AMD-41 reduction | Session write |
| `project/STAGE-6_BUILD_OPEN_QUESTIONS.md` | Disposition column added; the file marked ruled, contents preserved | Register edit |
| `ENGINEERING.md` | Index rows only: amendment count, §5 row, §7 registry count and item lists, §8 gate list | Index edit |
| `project/approvals/APR-012`, `APR-013` | **NEW** — the two recorded approvals | LAW-10 |

**Deliberately not touched:** every `.ai/core/**` byte and `.ai/adapters/**` byte · `.ai/BOOT.md` (the subject of AMD-41 §4 defect class A — **framework-only write access; not edited, and the determination says so**) · `project/BINDING.md` · `project/ledger/**` (`HEAD` remains at `genesis`, `seq 0`; `L-0000001` does not exist) · `core/MANIFEST.lock` (**not created** — Stage 6 remains unauthorized, OQ-14) · the distributable (**not created**) · `src/aief_stage6/**` and `tests/**` · `spec/**`, `AIEF-FRZ-001`, AMD-001…AMD-012, both ADRs, every schema, `ECR-D-001…004` · git history, tags, author or committer identity — no commit, tag or push is made by this session, and no attribution trailer of any kind is written anywhere.

---

## Separation of Duties — Recorded Tension

`core/agents/INDEX.md`: **`chief-systems-engineer` may not implement what it approved.** This instrument was ruled, and its manifest, registry and index edits applied, by the same authority (`chief-systems-engineer · S-2026-08-08-10`) at the direction of the human owner — `core/PRECEDENCE.md` rank 1, which outranks the rank-6 agent specification. Identical in form to the departures recorded in AMD-008 through AMD-012 §§ *Separation of Duties*; identically **authorised, not erased** (SOD-1).

| | |
|---|---|
| Duty separated | A4 rules and approves; A1 implements |
| Departure | A4 both ruled and applied |
| Authority for the departure | Live human-owner instruction of `S-2026-08-08-10`, rank 1, recorded per LAW-10 in APR-012 and APR-013 |
| Not departed from | The implementation delta AMD-45 requires in `src/aief_stage6/**` was **not** performed by this session. It is recorded as OI-C-09 for an A1 role. A4 ruling a construction and then writing the code that implements it is the departure this table exists to bound, and it was declined here |
| Mitigating control | Independent cold-context `qa-engineer` audit of this session's work — dispatched by the same directing authority; open until filed |
| Not mitigated by | Anything this document says about itself. Under LAW-05 an authority's assertion about its own work carries no evidentiary weight. In particular, AMD-41's re-measurement is this session's own evidence about a prior session's evidence, and needs independent recomputation before it is relied upon |

---

## Approvals Required and Recorded

| Change | Approval | Bound to |
|---|---|---|
| The manifest amendment of AMD-42…AMD-48, and re-registration of the manifest in `FROZEN.md` at its post-change digest | `project/approvals/APR-012` | the post-change manifest DC-1 digest (`subject_hash`), with the pre-change digest as `prior_hash` |
| Freeze-registry addition of this document (AMD-21 criterion: authorising instrument for a change to a frozen artifact) | `project/approvals/APR-013` | this document's DC-1 digest |

AMD-41 requires no approval of its own: it changes no frozen artifact. It is a determination and a reservation, and its authority is LAW-02 and LAW-12.

Per the AMD-16 design property, neither this document's own digest nor the post-registration DC-2 aggregate appears in this document; both live in the registry and the approval artifacts.

---

**END OF AIEF-AMD-013**

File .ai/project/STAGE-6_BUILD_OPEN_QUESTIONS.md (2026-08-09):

# Stage 6 Build — Open Questions for A4 Disposition

> **Instance artifact.** Partition `project`. Filed by `project-manager` action at rank-1 direction, session `S-2026-08-08-03`, per VER-006 FIND-Q6-2 and TCR-001 F2 — a single disposition subject for the implementation's undeclared details, which previously existed only in `src/aief_stage6/**` docstrings.
>
> Raised by `software.software-engineer · S-2026-08-08-07` during the CMP-BLOCK-004 build (LAW-12: flagged, not silently decided; deterministic interim choices are in force and disclosed in code). **None may be ruled by the session that raised it.** Each interim choice defines bytes of the first canonical `MANIFEST.lock`/distributable, so all five should be ruled before those bytes become the permanent integrity baseline.

> **ALL RULED — 2026-08-08.** Disposed by `chief-systems-engineer · S-2026-08-08-10`, a cold session differing from the raiser `software.software-engineer · S-2026-08-08-07` in **both role and session** (AMD-20 identity rule; the bar this file sets is satisfied and is confirmed in writing at [`AIEF-AMD-013`](../../framework/AIEF-AMD-013_Boot_Budget_Determination_and_Stage_6_Build_Constructions.md) § *Independence declaration*). Instrument §§AMD-42…AMD-48; approvals [`APR-012`](approvals/APR-012_Amend_Framework_Manifest_AMD-013.md), [`APR-013`](approvals/APR-013_Register_AIEF-AMD-013.md). Every ruling is a manifest change — **none was resolvable as an implementation-spec note**, because each defines octets of the first canonical `MANIFEST.lock` or distributable and so belongs in the single source of truth. **The questions and their interim choices are preserved verbatim below; nothing is removed.**

| # | Question | Interim choice in force (disclosed, deterministic) | Ruling |
|---|---|---|---|
| OQ-B1 | Lock JSON layout beyond the declared member order — indentation, key style, escaping | 2-space indent, LF, one terminal LF, `ensure_ascii` false | **AMD-43 — interim adopted and completed.** `core_aggregate.lock_json_layout`: 2-space indent per level, LF, exactly one terminal LF, no trailing whitespace, no space before and exactly one after the name separator, one member/element per line, **escaping only as RFC 8259 requires** (non-ASCII emitted as itself — the clause byte-identity turns on), emission order never sorted. Manifest change |
| OQ-B2 | `build_provenance` content — nowhere declared | Minimal deterministic set: source manifest DC-1, selected profile, stage, build id, run-fixed timestamp | **AMD-44 — interim adopted, closed and made explicit.** `build_provenance_record`: exactly six members in order — `source_manifest`, `source_manifest_dc1`, `selected_profile`, `compiler_stage`, `build_id`, `timestamp`. Host, user, working directory, tool/interpreter versions, per-execution wall-clock time and any environment capture are **prohibited**: each varies across the executions and platforms byte-identity requires to agree. Manifest change |
| OQ-B3 | Lock self-measurement fixed point — `files[manifest-lock]` carries token cap 200, but the budget record lives inside the lock; the lock's own count inside its own record is undefined | Lock row marked DEFERRED in the budget record; emitted lock text cap-checked post-serialisation, breach halts | **AMD-45 — interim adopted with one substantive correction.** `budget_measurement_record.lock_self_measurement`: row emitted `DEFERRED-SELF-MEASURED`, null counts, contributing nothing to totals; serialised octets cap-checked under both families post-serialisation, breach halts. **Correction:** the deferral is keyed on the path `core/MANIFEST.lock`, **never on absence from the tree** — closing the latent fail-open TCR-001 recorded as F1. Iteration to a fixed point and placeholder digits rejected with reasons. Manifest change; implementation delta owed as OI-C-09 |
| OQ-B4 | `distributable.contents` says "nothing else" while `determinism` declares a 0755 directory mode — tension | File-only tar entries; directory-mode rule treated as vacuous | **AMD-46 — interim adopted.** `distributable.entry_types`: regular file entries only — no directory, symlink, hardlink or device entry; extractors create directories from entry paths. `contents` governs; the 0755 clause is vacuous for a conforming archive and is **retained, not deleted**, so a future entry type does not inherit an undeclared mode. Manifest change |
| OQ-B5 | BINDING pin-line layout after the Stage 6 write (alignment, inline comment retention) | Value-token-only replacement | **AMD-47 — interim adopted and totalised.** `binding_pin_write`: replace the value token on the single `core_digest_pin` line, preserve **every other octet** including indentation, the whitespace run and the inline comment. Zero matching lines, multiple matching lines, or a non-hex64 candidate value each **halt the build**. Manifest change |

Also recorded by the SE, lower-order: DC-1 of a zero-length file is undefined by the line-wise wording (no covered or registered file is empty today); budget totals scope read as capped T0∪T1 files only (cap-null T1 files excluded) — confirm intent; AMD-33 byte-identity requires the timestamp/build-id be captured once per release run and shared across executions.

| Lower-order item | Ruling |
|---|---|
| DC-1 of a zero-length file | **AMD-48.** Content normalising to empty has the empty octet string as its preimage; DC-1 is `e3b0c44298fc1c149afbf4c8996fb92427ae41e4649b934ca495991b7852b855`. The terminal-LF step applies to surviving content, not to emptiness — otherwise an empty file and a one-blank-line file collapse to one digest. **No non-empty digest changes**, and the rule defines the digest without licensing the file (zero-dead-file rule stands). Manifest change |
| Budget totals scope | **AMD-42 — the interim reading is confirmed.** The measured set is exactly the non-null-`token_cap` T0∪T1 entries and clause 2's totals are the totals over that set: it is MI-4's own domain (Σ `token_cap` over T0∪T1) and the domain of `AIEF-FRZ-001` §1.8's Sum row of 5800 and Headroom row of 200. A cap-null entry declares no bound to measure against. **Residual raised, not glossed:** `project/ledger/HEAD` is read at boot step B4 yet is cap-null and therefore unmeasured — recorded as **OI-C-08**, expressly not cured because it draws on the same MI-4 headroom OQ-15 must allocate. Manifest change, plus a `validation[V-09].verifies` binding |
| AMD-33 timestamp / build-id capture | **AMD-48.** `build_time_reproducibility.run_fixed_values`: both are captured once per **release run**, before its first execution, and supplied unchanged to every execution — inputs, never outputs. A per-execution timestamp makes byte-identity unreachable by construction and turns AMD-33's halt into a permanent one, so this is the only reading under which AMD-33 is satisfiable at all. The release run, not the execution, is therefore the unit of provenance — which is why exactly these two values are admitted to `build_provenance`. Applies equally across V-10's platforms. Manifest change |

Authority: A4, a session distinct from `S-2026-08-08-07`. Instrument path: amendment or recorded ruling per LAW-01/LAW-10 where a frozen text is touched; several may be resolvable as implementation-spec notes without manifest change.

**Disposition of that authority note:** satisfied. The ruling session is `chief-systems-engineer · S-2026-08-08-10`. All eight items proved to require manifest changes rather than implementation-spec notes, and were taken through the LAW-01/LAW-10 path accordingly. This register is closed; its Closed row is in [`OPEN_ITEMS.md`](OPEN_ITEMS.md).

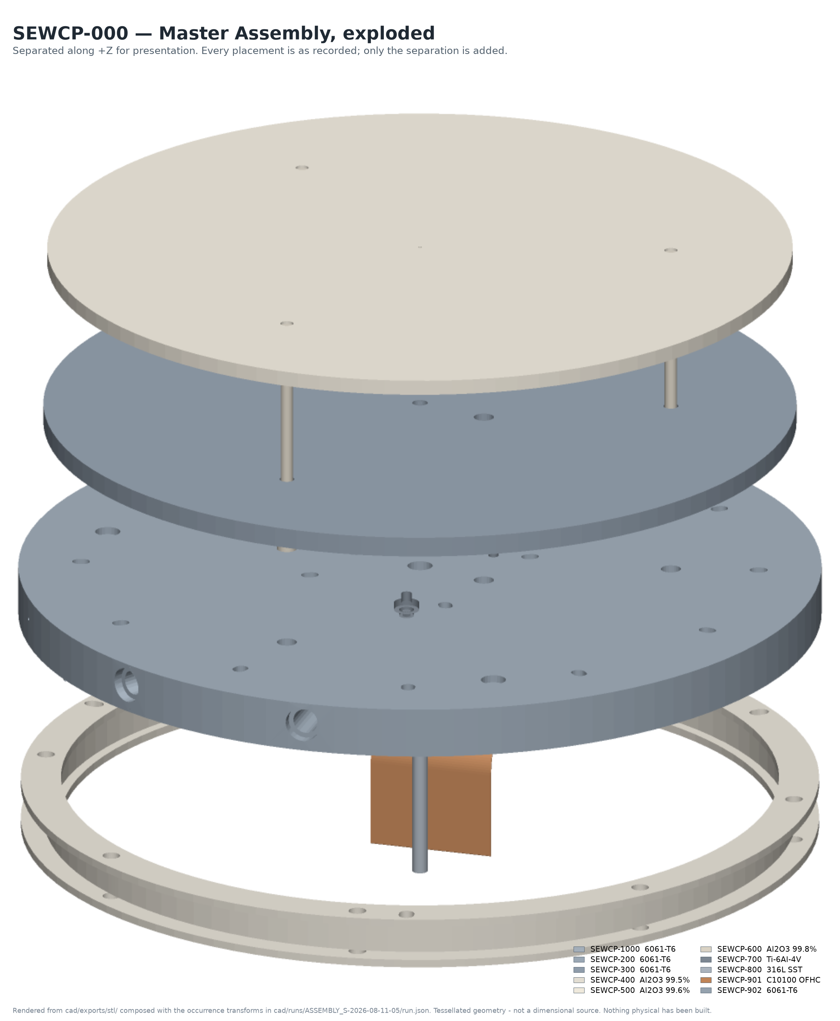
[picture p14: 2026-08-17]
portfolio/renders/SEWCP-000_assembly_exploded.png

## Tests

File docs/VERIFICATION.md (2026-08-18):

# Verification

*What was verified, how, and — stated with equal weight — what was not.*

All figures measured at release `v0.11.0`, commit `cad6ced6`.

---

## 1 · The distinction this document exists to protect

| | |
|---|---|
| **CAD / software verification** | **COMPLETE.** Every property that follows from geometry, material density and the repository's own artifacts is computed from observed evidence and reproduces from a clean clone |
| **Physical qualification** | **NOT STARTED.** No article has been built. 0 of 91 hardware-verifiable requirements verified |

These are not two degrees of the same thing. A model establishes *geometry and the properties
that follow from geometry and a density*. It establishes **nothing** about pressure drop, heat
transfer coefficient, leak rate, temperature uniformity, contact resistance, inductance,
particle generation, outgassing, cycle life, dielectric strength or dechuck behaviour.
Ninety-one of the 137 requirements are of that second kind (`PVR-001`).

---

## 2 · Observation-based verification

A verifier never reads whether the CAD command succeeded. It reads what Fusion says the model
*is*:

```
observed_model:
  bodies:     name · bbox_min · bbox_max · volume_mm3 · area_mm2 · mass_kg · material
  document:   name · persisted_name · units · design_type · saved
  component:  name · name_source · display_name
  parameters: name · expression · value · is_derived
  sketches · planes · features
```

Two rules make it honest:

1. **Absence is absence.** A body Fusion did not report is `None`, not a zero-volume body.
   A check over an absent subject reports `not present in the observed model. A check that
   cannot be evaluated has not passed.`
2. **No verifier reads `Observation.executed`.** A successful API call is the executing party's
   report on its own work.

---

## 3 · Acceptance criteria

Every finding is a five-field record, and they are all in the tracked run file:

| Field | Example |
|---|---|
| `id` | `ACC-VOL` |
| `subject` | `body:CP_BODY.volume_mm3` |
| `expected` | `1479108.9` |
| `observed` | `1479108.8648750156` |
| `requirement` | `CP-HANGER-TAP` |

`expected` is derived from the requirement package, never typed next to the answer. `observed`
comes back from Fusion. Neither can be edited into agreement without moving a digest.

### 3.1 Geometry verification

Bounding-box extents (`dx`, `dy`, `dz`), body count, volume, mass, material. Tolerances are
explicit and tight — the cooling plate volume check runs at **1 mm³ on a 1.48 × 10⁶ mm³ part**
(0.00007 %). Beyond the declared acceptance conditions, the verifier adds intrinsic checks —
*a solid was declared, so a body must exist; an extrude declared 8.0 mm, so `dz` must be 8.0* —
so a solution that declares no acceptance conditions is still not vacuously verified.

### 3.2 Interface verification

Named construction planes exist at their declared offsets; the locating sketches that later
features derive from exist and are fully constrained. A construction plane declared and absent
is reported as *"every feature that locates against it is unlocated"*.

An interface that the current bounded run does not build is reported **`deferred`** and named —
never silently passed. Where a run realises no interface at all, the verifier says so explicitly
rather than reporting a vacuous pass.

### 3.3 Parameter verification

`python -m aief_params check` → **105 parameters derived from §3**, exit 0.

At run time the constraint verifier adds three checks a value comparison alone would miss:

- every solution parameter **exists** in the model (`CON-PARAM-PRESENT`);
- every parameter **equals its resolved expression** (`CON-PARAM-VALUE`);
- a parameter the solution declares as a **derivation is still a derivation**
  (`CON-PARAM-DERIVED`) — a literal that happens to be numerically right has stopped tracking
  its source, and will not move when the source does.

Plus `CON-UNITS` — *"a document in another unit silently rescales every dimension in the
solution"* — and `CON-SKETCH-CONSTRAINED`.

### 3.4 System-level verification

| Record | Result |
|---|---|
| `cad/runs/SYSTEM_INTERFACES.json` | **12 / 12** — each with the computed gap, e.g. `IF-AP-CB` "AP flange Ø10.000 h6 in CP Ø10.000 H7 counterbore", gap +0.000 |
| `cad/runs/ASSEMBLY_S-2026-08-11-05/run.json` | **PASS** — 19 occurrences, each placed, grounded, with source design + version, observed bbox and mass; total **7.6997 kg** |
| `cad/runs/FINAL_SYSTEM_VERIFICATION.json` | **19 / 19**, `known_defects_carried: []` |

The 19 final checks cover the design registry, the assembly verdict and occurrence count, the
Z-station of every element of the stack against `spec/00` §4.2 (`SEWCP-400` [−0.3, 20.0],
`SEWCP-200` [20.0, 40.0], `SEWCP-300` [41.5, 49.5], `SEWCP-500` [49.9, 55.9], hanger [8.0, 20.0]),
the wafer plane at 55.920, the 12 interfaces, materials against spec, the four-way BOM
cross-check, the drawing set, four export digests recorded in the deliverable manifest, the
cooling-plate occurrence content, and — deliberately — that **every residue of the run is
registered as an open item**.

Its own definition of PASS is written into the file:

> *"PASS here means: every CAD-verifiable property of the final design verifies from observed
> evidence, and every non-verifiable or blocked item is explicitly carried."*

### 3.5 Feature clearance

`python -m aief_clearance` → **CLEARANCE OK**, exit 0. Checks `spec/00` §3.2 pair by pair on
bolt circles and angular positions, and **states what it skipped and why** — *"skip He / vacuum
central port: no bolt circle or no angles — not checked"*. A clearance check that silently omits
a pair is worse than one that omits it loudly.

---

## 4 · Provenance

| Layer | Construction |
|---|---|
| CAD commands, observations, verdicts | SHA-256 over a canonical byte form (UTF-8, sorted keys, no insignificant whitespace) |
| Run records | `sequence_digest`, `solution_digest`, `package_digest`, `record_digest` per run |
| Drawings | a provenance sidecar per document: **every dimension names its source** — `parameter:cp_od (params/generated/SEWCP-200.csv)` or `spec/00 §3.2 coolant 255°(in)/285°(out)`. **79 dimensions, 0 unsourced** |
| Deliverables | 61 files digest-registered in `cad/DELIVERABLES.md`, checked **both directions** |
| Freeze registry | 31 of 31 verify; DC-2 aggregate `1f32489a…8d45cc4b` |
| Framework core | boot step **B2a**: DC-1 over 75 covered files, DC-4 against the lock and `BINDING.core_digest_pin` — **75/75**, recomputed without importing the code being audited |
| History | hash-chained ledger, each entry linking `prev_hash` |

---

## 5 · Independent QA

LAW-05: **no role verifies its own output.** Independence is supplied by a **cold-context
session** that reconstructs every fact from the repository, imports nothing from the code it is
auditing, and writes no repository file — or the item stays open.

Five rounds ran against this release. **Four returned `NOT CLEARED`**, and each found a real
defect in a repair that looked complete. Two of their recomputations contradicted the repository
and were right. Full account: [`QA.md`](QA.md).

---

## 6 · Release verification

Reproduce from a clean clone:

```bash
PYTHONPATH=src python -m aief_gate            # LC-M04 CAD-READY: YES              exit 0
PYTHONPATH=src python -m aief_clearance       # CLEARANCE OK                       exit 0
PYTHONPATH=src python -m aief_params check    # PARAMETERS OK  105                 exit 0
PYTHONPATH=src python -m aief_approval verify # APPROVAL CHAINS OK                 exit 0
PYTHONPATH=src python -m aief_deliverables    # 61 registered, 61 reproduce        exit 0
PYTHONPATH=src python -m aief_register        # REGISTERS OK                       exit 0
PYTHONPATH=src python -m pytest tests/ -q     # 843 passed, 52 skipped, 0 failed
PYTHONPATH=src python -m aief_analysis        # 4 of 5 FAIL — ECR-D-016            exit 1
PYTHONPATH=src python -m aief_stage6          # HALTS: tokenizer artifacts absent  exit 1
PYTHONPATH=src python -m aief_exec check      # 7 of 10 PASS                       exit 1
```

Measured three ways at `cad6ced6`:

| Environment | Result |
|---|---|
| Clean clone of the published repository | **843 passed, 52 skipped, 0 failed** |
| Clean clone + both tokenizer artifacts + TOFU record | **894 passed, 1 skipped, 0 failed** |
| Working tree (artifacts and `build/stage6/detcheck/` present) | **895 passed, 0 skipped, 0 failed** |

The 52 skips measure token budgets through two normative tokenizer families whose artifacts are
third-party binaries and are not tracked. Nothing estimates in their absence —
`budget_measurement_record` rules that absence **blocks** rather than estimates — so they skip
rather than guess. One test needs `build/stage6/detcheck/`, which is gitignored and which no
code in the repository creates, so it is unreachable from a clone by any route; it is the single
remaining skip once the tokenizers are provisioned.

**This gap was itself a defect, found the only way it could be.** Until session `S-2026-08-17-01`
these tests had no skip guard and **failed** on a clone while passing at the desk — so the
README claimed a reproducibility that had never been tested from outside. Recorded as `OI-V-16`;
the GitHub Actions `validate` workflow now runs the battery on a runner, where there is no
author's machine to be lucky on.

**What a clone cannot reproduce at all.** The Fusion designs live in Autodesk cloud versioning,
so regenerating `cad/` requires Fusion 360 with the add-in installed. Everything else — every
gate, every digest, the drawing set, the BOM and the whole test suite — runs offline.

---

## 7 · Physical qualification — the boundary, stated plainly

`PVR-001` is the record, and it contains **no test result**, because no hardware exists.

| | Count |
|---|---|
| Numbered component requirements, Volumes 01–09 | **137** |
| `DESK-DISCHARGEABLE` — method is design, drawing, analysis or calculation | **46** |
| **Hardware required** | **91** (46 + 91 = 137; the classes partition the set) |
| — of which hybrid (instrument *and* analysis) | 7, counted inside the 91 |
| **Verified by physical evidence today** | **0** |

Its status vocabulary is a closed set, and `VERIFIED` is **used nowhere in the file**.

### The four mass rows are predictions, and are labelled as such

| ID | Limit | Model | Margin | Status |
|---|---|---|---|---|
| `CP-15` | ≤ 4.2 kg | 3.9936 kg | −4.9 % | `MODEL-PREDICTED` |
| `HP-18` | ≤ 1.6 kg | 1.2338 kg | −22.9 % | `MODEL-PREDICTED` |
| `SR-15` | ≤ 0.8 kg | 0.5168 kg | −35.4 % | `MODEL-PREDICTED` |
| `EC-18` | ≤ 1.7 kg | 1.6196 kg | −4.7 % | `MODEL-PREDICTED` |

The declared verification method for all four is **Scale**. A scale needs a part. Two of the
four sit within 5 % of their limit, so machining tolerance and surface treatment mass are
consumable margin, not comfortable margin — and the record says so.

### One defect is open against the design itself

`ECR-D-016` — the Support Ring isolation joint does not close. Computed by
`python -m aief_analysis`:

| | Required | Computed |
|---|---|---|
| `SR-04` clearance | ≥ 12.00 mm | **8.50 mm** — the greatest value any hardware choice can offer |
| `SR-03` creepage | ≥ 20.00 mm | **14.00 mm** as modelled; **17.42 mm** with `SR-D12`'s R3.0 fillets present |
| `SR-02` shunt impedance at 13.56 MHz | ≥ 400 Ω | **353.94 Ω** |

One root cause: `spec/03` §2.1 and §3.1 compute the flange gap as empty while §5.2 puts a
6.00 mm grounded ring inside it. The arithmetic was proven against the specification's own
published answer, and an independent round attacked it with five counter-readings — all five
died. Ruled **disposition A: Rev B baseline revision**, remedy computed and published *with its
own defects recorded*, and **deliberately not implemented**, because implementing it is a
specification re-baseline rather than a release action.

**Do not build to this baseline.**

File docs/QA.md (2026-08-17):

# Independent QA

*Five cold-context rounds ran against this release. **Four returned `NOT CLEARED`.** This
document exists to say what they found, not to say that everything was fine.*

---

## 1 · The rule that makes it worth anything

**LAW-05 — no role verifies its own output.**

The failure mode this is aimed at is not dishonesty; it is that the party who repaired a defect
is the worst-placed party to judge whether the repair worked, because they will check for the
defect they were thinking about. So independence is supplied structurally:

| Requirement | How it is met |
|---|---|
| The auditor must not inherit the author's beliefs | a **cold context** that reconstructs every fact from the repository, with no conversation history |
| The auditor must not trust the audited code | it **recomputes** digests, aggregates and counts **without importing** `src/aief_stage6` or the module under review |
| The auditor must not become an author | it **writes no repository file**; it returns a verdict the repairing session did not choose |
| The verdict must be able to be "no" | it was, four times out of five |

Across five rounds, `qa-engineer` was assigned to **none** of the repairing sessions. Each
session record says so explicitly, and says which acts it *was* performing instead.

## 2 · Why QA is not decorative here

Four defect classes went unnoticed for many sessions in this project. **Every one of them was a
declared property with no standing check** — something a document asserted and no code computed.
Independent review is the only instrument that finds that class, because the tests were written
by the same reasoning that wrote the claim.

Two of the rounds' recomputations **contradicted the repository and were right**:

- the deliverables were **not** byte-identical to the generation root, though the record said so;
- the test suite did **not** pass from a clean clone — a clone got **35 failures** while the
  author's desk passed 846.

Both were corrected. The second produced `OI-V-16` and the GitHub Actions `validate` workflow,
whose stated purpose is written into the file: *"CI exists so that a claim in `README.md` is
falsifiable by a stranger, not so that a badge is green."*

---

## 3 · The five rounds

The subject was `ECR-D-014` — a framework ruling capping a boot-read token prefix at 200 tokens.
Small, dull, and exactly the kind of rule a release session could have quietly waved through.

| Round | Verdict | What it found |
|---|---|---|
| **1** | `NOT CLEARED` | Cleared `ECR-D-006`. Refused this one: **the ruling was enforced by nothing.** Three call-site mutations survived all **799** tests |
| **2** | `NOT CLEARED` | The round-1 repair was enforced **only on the preview path**. A mutation skipping the cap check when `canonical` is true survived all **846** tests, and the canonical build then wrote `MANIFEST.lock` with a **249-token prefix against a cap of 200**. Root cause: **no test had ever called `run()` with an `Authorization`** — the path that writes canonical bytes had no end-to-end test at all |
| **3** | `NOT CLEARED` | Enforcement **fully discharged** — it applied fifteen mutations, six of them new (deleting the post-condition, truncating so both derivations agree on a wrong region, returning early, clamping instead of raising, comparing the record to itself, exploiting the stub probe's leniency). **All fifteen die.** Refused closure on record accuracy alone |
| **4** | `NOT CLEARED` | **The check written to end a recurring defect did not catch that defect.** Its pattern was line-scoped and the defect's own phrasing spans two lines, so the *verbatim* historical defect passed all seven tests. Of nine phrasings tried, **2 caught, 7 evaded**. Its self-test was **circular** — validating the pattern against a string written for the pattern |
| **5** | **close** | Re-proved the substance again, and found the rebuilt check *still* incomplete: of **thirteen** phrasings, **twelve got past it** — including `last_ledger_seq: 2`, the field's own name, because there is no word boundary after an underscore. Seven of nine governing sections unscanned; the fenced YAML block that *is* the governed state skipped entirely; and one test still circular. **Recommended closure with named residuals** |

`ECR-D-014` was closed on round 5's own recommendation — a `qa-engineer` act, in a distinct cold
session. The closure basis names all five rounds.

## 4 · What the closure says, and what it does not

**Says:** the ruling is sound and was independently re-proved three times; its enforcement is
real and survived fifteen mutations plus six more; LAW-02 clause 5 and LAW-05 are satisfied
because **no session that repaired it certified its own repair, across four consecutive
attempts.**

**Does not say the repair sessions were clean. They were not.**

> **Four consecutive repair sessions each introduced a defect of the class they were repairing.**

That is a process finding, it is real, it is recorded at `OI-V-17`, and **it is not closed by
this release.** It is written into the release-readiness report and the session summary in those
words. Holding the ECR open a sixth time would have made it the carrier for a defect class it
does not own.

## 5 · Findings the rounds produced that were not about `ECR-D-014`

The rounds audited whatever they found, which is the point of not scoping them narrowly:

- **`LICENSE` §1 asserted the negation of the property the licence turns on.** A half-replaced
  edit left the sentence *"No tracked file falls in exactly one column"*, contradicting §1a in the
  same document. Round 4 caught it by classifying **every tracked file** and measuring 0 in
  neither column and 0 in both.
- **`LICENSE` §2's *"nothing in the set is copyleft"* was wrong** — `certifi` is MPL-2.0. The
  conclusion survived on the correct ground: nothing is vendored, modified or redistributed.
- **`TCR-002` has eight findings, three BLOCKING** — not six and two, as three artifacts said.
  `F-7` and `F-8` had been carried nowhere, dropped by `OI-V-14`, *the item raised to stop
  findings being dropped.*
- **A ledger entry's narrative body was the previous entry's prose with the identifiers
  incremented.** Every field covered by the digest construction is correct, the digest
  recomputes and the chain links — but the human-readable *account* described the wrong session.
  Because the artifact is append-only, **it was left standing, wrong, and annotated** rather
  than rewritten: *"A false account that is left standing and annotated is a smaller failure than
  a corrected one that leaves no trace."*
- **The `README.md` reproduction claim** — corrected twice, and it is corrected again in this
  pass (see [`DOCUMENTATION_FINDINGS.md`](DOCUMENTATION_FINDINGS.md)).

## 6 · The finding the process could not absorb

`.ai/project/OPEN_ITEMS.md` is a bounded index with a **600-token cap**, standing at **597**
against a marginal cost of about five tokens per identifier. Twice, a new open item was raised,
breached the cap, halted validation rule `V-09`, and had to be **withdrawn and folded** into a
row that already carried its class.

**Three findings in three sessions were denied an identifier of their own.** Each fold is
defensible on the merits and each is recorded as **budget-forced rather than chosen** — because
a register that merges findings to stay inside a cap has stopped being a register of findings.

That is `OI-C-10`, and it is honest about being unsolved: no session-level action remains, the
lawful successors are named at the row, and it is now blocking *the next* finding.

---

## 7 · What a reader should take from this

Not *"QA passed."* It mostly did not.

The claim is narrower and more defensible: **an adversarial reviewer, given the repository and
nothing else, was able to falsify the engineering team's conclusions five times running, and the
process recorded every one of them instead of quietly repairing and re-declaring success.**

The release-readiness report puts it in its own words:

> *"Every standing check is green and […] tests pass. **That is not the same as ready.** Nothing
> physical has been built or measured; 91 requirements await hardware; one joint of the design is
> known not to close, and the framework's own `ECR-D-014` is open on a rule this session could
> have quietly ignored. The green is real, it is broader than it was, and it is still narrow."*

*(The elided figure is the suite count as it stood when that section was written; the measured
count at `v0.11.0` is 895 local / 843 from a clean clone, and `ECR-D-014` has since closed —
[`DOCUMENTATION_FINDINGS.md`](DOCUMENTATION_FINDINGS.md) §3.)*

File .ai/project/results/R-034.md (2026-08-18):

# R-034 — R-032 Republished After the Independent Publication-Readiness Audit's Documentation Repairs

> **Instance artifact.** Partition `project`. Owner `project-manager`.
> Result record per [`../EXECUTION_ARCHITECTURE.md`](../EXECUTION_ARCHITECTURE.md) §6.
> **Supersedes [`R-032`](R-032.md)**, sealed below at the DC-1 it now stands at.

```yaml
result_id:   R-034
produced_by:
  task:      T-012
  role:      repository-engineer
  session:   S-2026-08-18-03
status:      CURRENT
supersedes:  R-032
supersedes_seal:
  path:   .ai/project/results/R-032.md
  digest: 16932de1a837c6f8dc4aa4b4aa13476cd4fbea0d2ebba93a7af6a5009c5dd87e

inputs:
    - path: .ai/project/verification/PVR-001_Physical_Verification_Record_And_Test_Matrix.md
      digest: caed10ac28ddf60876b78a3f5ce836ceddc2fd8a77daad74393df8c75498e9c3
    - path: .ai/project/ecr/ECR-D-018_Local_Account_Name_Becomes_New_Public_Information_At_Publication.md
      digest: 764bf92a654a93f6a8377f046cd55aab86addb52d1ab71086cbc37dfdd32d525
    - path: .ai/project/HISTORY_REMAP.md
      digest: f8e779a1c47072f4f7dbacab901b6b5d5b8a6963656e1a4c98ddab7dd80a4efd

deliverables:
    - path: .ai/project/HISTORY_REMAP.md
      digest: f8e779a1c47072f4f7dbacab901b6b5d5b8a6963656e1a4c98ddab7dd80a4efd
    - path: .ai/project/STATE_REGISTER.md
      digest: bb5a58aba99842150abab96d35262eda9af15116a8a968ea98fbeb14d5020802
    - path: .ai/project/approvals/APR-039_Rank-1_Override_LAW-07_For_ECR-D-018_Sanitization.md
      digest: c2387e7f55a7a980e7b17c33612e610996b8a9e4823a7c816bf50ff1aa9d72fa
    - path: .ai/project/decisions/DECISIONS_S-2026-08-18-02.md
      digest: 2f53d2b24d6acd496a3293b9143bc3ad428a82dea5045ec630397194f27ae164
    - path: .ai/project/ecr/ECR-D-018_Local_Account_Name_Becomes_New_Public_Information_At_Publication.md
      digest: 764bf92a654a93f6a8377f046cd55aab86addb52d1ab71086cbc37dfdd32d525
    - path: .ai/project/ecr/ECR-Q-016_Whether_Published_History_In_LAW-07_Means_Pushed_Or_Public.md
      digest: 4d2265f2a5f50c008a3ab0f0977155876ca47c087ee004774ff3ede7e716567b
    - path: .ai/project/verification/PVR-001_Physical_Verification_Record_And_Test_Matrix.md
      digest: caed10ac28ddf60876b78a3f5ce836ceddc2fd8a77daad74393df8c75498e9c3
    - path: .gitattributes
      digest: 8eba9f4a3e8534cded8339fc2206824e2d7a72314c3cdc45af4b127ee39cef88
    - path: .github/workflows/validate.yml
      digest: a9d2edad82204a743a3a5ace65ff97f452584695b54d171be98767ebe464e693
    - path: CHANGELOG.md
      digest: 270272118df40107407900c252f4214d3f72a70225eb2f933c9eb82bc173fad4
    - path: CONTRIBUTING.md
      digest: 00a27b3d2dba319bf3af485177818cdf8f5722e8a6b22cf33a470c51269df1a3
    - path: ENGINEERING.md
      digest: ef4d0e96e93029c9ff0d628dd418c6fcd9b32609c6d6ee14c8494218534365ea
    - path: LICENSE
      digest: 5cfaeb62bac91b98232d0b1b318dee388bc9bd102c9b5632963f34c6c980b3c2
    - path: README.md
      digest: ed245211f9e18d23cbe7cea8e51642f28ff9e3f9581ca1ef4bfcdf4312d9d10f
    - path: analysis/SEDEP-RPT-003_structural/SR-07_AP-08_as_modelled_mass.md
      digest: 02078586b3a93e4f0ca5994928191704fbdff649447ed2e7e3fc04ebd57ca140
    - path: analysis/SEDEP-RPT-004_electrical_rf/SR-02_SR-03_SR-04_insulation_trace.md
      digest: 2fa7d3fa89947bda19019f46bf8a6a1fcb0684b3d6b9b07b4d082ecf1e5f874e
    - path: cad/DELIVERABLES.md
      digest: 0d07836d1151363e5fba4e47f2cc50a7ffa2b9a6644d3bfe4b0fe331248033ec
    - path: cad/LINEAGE_CENSUS.md
      digest: c282fe7a4af935ecb4fe6e55482fa78c5a402de706bcbe55b671f96ddaea6c7e
    - path: docs/ARCHITECTURE.md
      digest: 0af96cfce3afa50ac4981121d4787d69e50f965ea42b04b9717ed4eb9c2c1413
    - path: docs/DELIVERABLES.md
      digest: b7ef4551379ec744e3614c50c4a4b62084e23d2943b7b9599f7cb79b32862323
    - path: docs/DOCUMENTATION_FINDINGS.md
      digest: d75b88e295d7cbe3cffd059ec07f39987b32904b7b94a14bc65791ea5d686fc2
    - path: docs/FAILURE_RECOVERY.md
      digest: 26cd482731fc6488290af462fc8d5422cc136445af6dab57192beda430e4dc37
    - path: docs/INTERVIEW_STORY.md
      digest: bbf1ca537c1c14b669a4e5139309029654d0d6d788126bb8250ae75e5d26cc57
    - path: docs/LINKEDIN_POST.md
      digest: dc92ab79dfdc0f519daa129411dab5eef6936e79b3383e066758dc363abe7873
    - path: docs/PORTFOLIO_ASSETS.md
      digest: 6b80d91d7a0bc941aee83e47017770d751ad6531a809a160905daa5b628ade5b
    - path: docs/QA.md
      digest: 3d4d66ecbe3b06922e0392df9dd97a423a44b0143c0631c4979019384623324b
    - path: docs/README.md
      digest: c6c935b3eb68297e45b9e06cc072d601fcd032b34954f6bf59a16969820bd0f3
    - path: docs/RECRUITER_OVERVIEW.md
      digest: 983c38947e6a09d2e3c9a0676cb67d061588f499286b9365cec72ea34818c8f3
    - path: docs/RELEASE.md
      digest: ea3ab41bb553452afd42ac60cf9eedd7c8ceecfb10b1f59f885ca7b54b4a157d
    - path: docs/RESUME_BULLETS.md
      digest: 6df6d1d2d6ce2e24b5545816de4a0db141429a5feb8a0cca0673dcfb718e20e9
    - path: docs/VERIFICATION.md
      digest: 9ba7c021c6f2e6876d6abb1d68dd36a7540a8f7cc397d0df242bb93c60b9c370
    - path: docs/assets/architecture.svg
      digest: 8df3c7685f7c22f020203c41b732a57646f9ded0d64d05039bf7eae70bcbefae
    - path: framework/AIEF-AMD-015_Lock_Boot_Read_Prefix_And_Member_Order.md
      digest: 195302214a14ab38d9c595dee35c5eb6a930f5f90c4c70854488ff62207c6ae4
    - path: framework/framework.manifest.json
      digest: 759f774b727c43a0f96845aa5ac12a05a1158b60c27ba8b31d963a33cde74e3b
    - path: implementation/01_SEWCP-200_Cooling_Plate/SEWCP-200_CAD_Implementation_Package.md
      digest: 2f58beec9b8cba5cbf19e5f9ff96ffad64b49203cc20993420ada12fc0da4955
    - path: params/generated/SEWCP-200.csv
      digest: 5434421dd781169fa7e47d4ec78bad310943d0f58a3999cb1619006587beb27f
    - path: releases/GITHUB_RELEASE_NOTES_v0.11.0.md
      digest: 63c222bb7d2f986531b36649aa125c1d08275d17cf2f08c7794b9fee336c2583
    - path: releases/RELEASE_READINESS_v0.11.0.md
      digest: 8329e459e57f0de5286cfa2164291b8ccfe3b90905e8cb70e98d7ec4ec0dd369
    - path: requirements.txt
      digest: 6027c667306b0588154e0021629ae198baf94d65ea05d6cccf4f51ffcfe87224
    - path: scripts/render_assembly.py
      digest: 9f23346143bc81739b0f7e24f4be550df288815ea18bdbc4cb96ee006bf66928
    - path: spec/00_SEWCP-ENG-001_Architecture_and_Interface_Control.md
      digest: fa2a84ccf3a837176eade00c502916a7a1492c9c58785448a4c26ba0fbaab95d
    - path: spec/01_SEWCP-200_Cooling_Plate.md
      digest: a3afa3eb41ee2aba7181fc4ae778a29d12c396194f1252640cc4e02e4b9f2230
    - path: spec/02_SEWCP-300_Heater_Plate.md
      digest: 0290580066829963de1c9bbbd059f5f088e442031d679cf4ddf5046693d66aef
    - path: spec/03_SEWCP-400_Chuck_Support_Ring.md
      digest: a2f951a1c749b688141d8245f8575ed6aabf28df03b55788a0d762f4e6c7dcbf
    - path: spec/06_SEWCP-700_Alignment_Pins.md
      digest: 75cda88184e5ae50acd05fb86dfb61ffc6238219462e8854120c05f14d04f396
    - path: spec/07_SEWCP-800_Vacuum_Port.md
      digest: 7558bc5b0f613ab9184d66dba6afd6674214d33302775eee2515bd25c8122afe
    - path: spec/08_SEWCP-900_RF_Feedthrough_Bracket.md
      digest: 710f6e14bf8b40498a4ec91ea65b760fc55eea99507513a93feb85bb6aa55414
    - path: spec/README.md
      digest: 1d7720723ddd42028a9536ec20cfb50a9a8b803bc3172423b31f108a7f93416c
    - path: src/aief_analysis/insulation.py
      digest: 77c7499be3028655ebc36d558b743fd465e9ff55f775ce477b2a19786ccb8b76
    - path: src/aief_analysis/loads.py
      digest: a225c235ca1083506eb2209c0d7a3a7f6950373ffb0d0215733509f04408bfa0
    - path: src/aief_approval/chain.py
      digest: a8b25ececce1eb1d60047b58e69fe017767d77fcf262d407a8e9e707c264326b
    - path: src/aief_clearance/check.py
      digest: 1b5c08cccb2344f0ba53e61718ccdf708cdc23eef01525f6b88ae447c919fb85
    - path: src/aief_deliverables/check.py
      digest: 6c81580be9386d0849f6d54988af2c82ecd732cf15947569bc03ded216eb5582
    - path: src/aief_draw/pdf.py
      digest: cf82f82f21903fec5da7975be9237b8cb1f057edd6ccdceac1a4dfd6a258423e
    - path: src/aief_gate/criteria.py
      digest: 2e13c1b7868f7457cdaaee4106057c5d9096129d5b58ee391ca236940622f85e
    - path: src/aief_params/__init__.py
      digest: df1edf0448052821bac5c0d6535c9f72c46c5bffbc3a20e6eb0100c1fcb1f690
    - path: src/aief_params/__main__.py
      digest: 711a4965f38d790e6322afe17a1f8b545097dfbd7ce541f2d9a81f18deb4680e
    - path: src/aief_params/extract.py
      digest: e27295056c30b59f5b5a617b625fe617914ae9448033a2d83475219d20c7b636
    - path: src/aief_register/check.py
      digest: afdb3d6ea7235e84b7b002f9c726f31740f567031aa63f7fdcc7de2f61ead968
    - path: src/aief_stage6/budget.py
      digest: e3fba6618656ddbf219c1258b5f7f908de831d3bf4c67477246367734938ce1a
    - path: src/aief_stage6/build.py
      digest: 0f958556b6e857131597d965da7382775f91bd23ba55a868cd53bc139a8791e8
    - path: src/aief_stage6/lock.py
      digest: 4cb525b066f6c282376616b1e60e022c4f07a6e04f49473bde3fe96cf10dd5f8
    - path: src/aief_stage6/paths.py
      digest: 1eac71322a29f85348c88f1cae126099fefb01518b2667ea181b6824eccc84d8
    - path: src/aief_stage6/preconditions.py
      digest: 6c08486cbb17f4513bd5b6ec92261d85a737ea27c3979a7fab193a98667cb324
    - path: src/sedep/bom/builder.py
      digest: 7b8e0bac22ecc260580022572d913703ad68813cb34d61ac12e474ef319eb07a
    - path: tests/test_analysis_oi_c_15.py
      digest: a8f039a19dd9aa7cbb60b18c084a85a4ef91e093bf97749c864be0b68348efc3
    - path: tests/test_approval_chain.py
      digest: e8b9973da32d9eb4c9a8f0657d7de5f150545bdd1509dd7967171ac56320c801
    - path: tests/test_bounded_register_split.py
      digest: a62628bdb08e6e56dceee9e035fffb8e0ca23200cd1fc1273ca742539bf8b092
    - path: tests/test_clearance.py
      digest: 3f411f4c149adb6d547d52fbcbbabe03a47420f9fabf07af8c8a8679b3e6e4ae
    - path: tests/test_deliverables.py
      digest: 09af3f532e37875f329c176997f0293b189152e32f270d08d61b8fc8597a47e2
    - path: tests/test_exec_checks.py
      digest: f9c6a263a83a3294791b85aea1db40f15e9f6cac336638ac1631d122c48b018e
    - path: tests/test_exec_scope.py
      digest: 8246e8ff39536819a1cb3e167d219f4d4109b2c6ccf9d5e003853ce3cef15b38
    - path: tests/test_params_export.py
      digest: 492abe55a12e535e32905c0a5d45da29ba508a3c8ed0d6d2bbf1ef605e9b6cc1
    - path: tests/test_physical_verification_record.py
      digest: 6f8ac7f2637a4d6a3e927f76de92b36622cc9ee9e54a592551879268ba2c97a8
    - path: tests/test_stage6_certification_lock_archive_guard.py
      digest: 8d7400579897ba6fd969a72868523e653acf2d1d772e64449af1a042c5337d63
    - path: tests/test_stage6_pipeline_stub.py
      digest: 102b7b86778a8614077c2cd41ff6f3f5e9ee70bb342c97c6518fd259928639d4
    - path: tests/test_stage6_prefix_enforcement.py
      digest: 69c2469f238cf96cbb07d68aa0190693852cfcf14c0f65b34be8648a767dd00a
    - path: tests/test_state_register_currency.py
      digest: 40415824ca88aa1dac0f58fe9ff46f20a00bfd2d7a00b90313f6cfdcfe79be33
    - path: tests/test_verification_chain.py
      digest: 5ba1ad803a371371cabfb891c1b4e22d72d33d5c3bc8610e6f7f9c78b798bd0f

conclusion: |
  R-032 staled the moment this session's documentation-accuracy repair changed the bytes of five
  files it pinned. That is the drift detector working, not a defect. This record republishes
  every pin against the repaired tree. Correction is by supersession and never by mutation:
  R-032 received its closing edit - status SUPERSEDED, superseded_by R-034 - and nothing else,
  and is sealed here at the DC-1 it now stands at.

  WHAT CHANGED, AND ON WHAT EVIDENCE. Three defects, all documentation-accuracy, none security,
  license, or governance:

  (1) ENGINEERING.md and program/SEDEP-PMP-002_Digital_Engineering_Infrastructure.md both
  claimed 142 requirements. PVR-001 section 1 records the governing figure as 137, parsed
  mechanically from spec/01...spec/09 at frozen_set_hash 701db1fd...f618aa50, itemised
  15+19+15+18+14+12+14+15+15. Every portfolio document already read 137. SEDEP-PMP-002's own
  citation - traceability/rtm.csv - does not exist in the repository; that gap is reported here,
  not repaired, because fabricating the file would be inventing evidence.

  (2) README.md, docs/README.md, docs/RECRUITER_OVERVIEW.md and docs/VERIFICATION.md named
  f8ff028 as the release commit alongside v0.11.0. v0.11.0 targets cad6ced6 - both locally, per
  HISTORY_REMAP.md's remap table, and per README.md's own Release section, which already read
  cad6ced6 two hundred lines below the line this record corrects. R-031 established that every
  engineering-relevant path is byte-identical between the two commits, so no figure in these
  four documents changes in value - only the commit identifying which release they belong to.
  Every other f8ff028 occurrence in the repository was independently classified and left
  standing: HISTORY_REMAP.md's remap table, DOCUMENTATION_FINDINGS.md's audit trail, the ECR/
  session/result records narrating what was true when written, and docs/RELEASE.md's and this
  README's own still-true statement that origin/main has not yet been force-updated.

  (3) ENGINEERING.md section 7 read PUBLIC. R-032 finding F-3 had already recorded this defect
  and left it unrepaired as outside T-011's write scope. `gh repo view --json isPrivate` and
  STATE.md both give PRIVATE. The cell now reads PRIVATE, with the pushed-to-origin/publicly-
  visible conflation ECR-D-018 section 2.3 named spelled out rather than silently dropped.

  WHAT WAS EVALUATED AND LEFT UNCHANGED. The advisory finding that
  `D:\Fusion Projects\SEWCP_Master_Assembly` - drive letter and folder name, no username -
  appears in eight current-tree files was reviewed and NOT redacted. All eight occurrences are
  inside independent-verification evidence (VER-001, VER-002, VER-004, VER-006, VER-007, VER-009,
  TCR-002) or a closed-incident procedure record (cad/BRIDGE_RESUME.md), each recording exactly
  what repository path and command a cold-context auditor or recovery procedure used. Editing a
  literal evidence transcript to remove a non-identifying path costs the record's authenticity
  for no privacy gain the account-name sanitization did not already deliver. No history rewrite
  was performed or considered for this; the decision is to preserve, not redact.

  WHAT THIS SESSION DID NOT DO. No engineering, CAD, specification or governed-verification
  artifact was created, modified or deleted. No git history was rewritten, no ref was pushed or
  force-updated, no tag was moved, and GitHub visibility was not touched - the repository remains
  PRIVATE. No test or check was weakened, skipped or deleted to obtain a green result. No
  approval instrument was filed, because no LAW-01 frozen artifact and no law rule is overridden
  by a documentation-accuracy correction; authority for the edits is the live owner instruction
  this session records in full.

findings:
  - id: F-1
    finding: |
      The independent publication-readiness audit that identified BLOCK-1/2/3 ran as four
      parallel read-only reviews within the same overarching session that then authorised this
      repair, not as a separately-filed cold-context round. LAW-05's independent-verification
      requirement for T-011's own sanitization work, and now for this repair, remains OWED and
      is not discharged by that audit.
  - id: F-2
    finding: |
      This record's own inputs list PVR-001, ECR-D-018 and HISTORY_REMAP.md as the governing
      evidence for the three corrections, rather than a filed decision or ECR document, because
      none was filed - the owner's authorisation was a live instruction recorded at
      S-2026-08-18-03, not a written DECISIONS_*.md. This is noted rather than concealed behind
      a synthesised approval instrument.
  - id: F-3
    finding: |
      A second-round audit of this session's own repair, run before this record's final
      publication, found the BLOCK-1/BLOCK-2 grep pass had not been exhaustive: two further
      142-requirement occurrences in program/SEDEP-PMP-002_Digital_Engineering_Infrastructure.md
      (lines 531, 541 - different phrasings, "142 traced requirements" and
      "142-requirement engineering specification", missed by the pattern that caught line 567)
      and one further f8ff028 occurrence in docs/VERIFICATION.md line 169 ("Measured three ways
      at f8ff028:"), which had come to directly contradict that same file's own line 5, already
      corrected to cad6ced6. All three are fixed in the tree this record pins; docs/VERIFICATION.md's
      digest above reflects the second edit, not the first. One further "142" was found and
      deliberately left alone: program/SEDEP-PMP-001_Program_Management_Plan.md line 811, inside
      an illustrative SEDEP dashboard mockup dated 2026-10-09 showing a hypothetical mid-program
      state (gate G2 pending, several components below 100%) that does not describe the actual,
      completed current state - a self-consistent example total (89+38+15=142), not a stale
      current-state assertion, and therefore out of this correction's scope.
```

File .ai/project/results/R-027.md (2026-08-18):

# R-027 — R-023 Republished After the `needs_artifacts` Guard Moved Two Pinned Tests

> **Instance artifact.** Partition `project`. Owner `project-manager`.
> Result record per [`../EXECUTION_ARCHITECTURE.md`](../EXECUTION_ARCHITECTURE.md) §6.
> **Supersedes [`R-023`](R-023.md)**, which pins `tests/test_exec_scope.py` and
> `tests/test_exec_checks.py` — the two modules the `OI-V-16` repair guarded. `R-023` is
> retained unedited apart from the two supersession fields and sealed below.
> Consume the `conclusion`.

```yaml
result_id:   R-027
produced_by:
  task:      T-009
  role:      software.test-engineer
  session:   S-2026-08-17-02
status:      SUPERSEDED
superseded_by: R-033
supersedes:  R-023
supersedes_seal:
  path:   .ai/project/results/R-023.md
  digest: 348079b1c325d0750cf2bb09e57ef3ad1a22c11736c6a37ea9db4055ad23e689

inputs:

deliverables:
    - path: .ai/project/EXECUTION_ARCHITECTURE.md
      digest: bb81925dc76f0163e790f572513caeaee1345bcb3b9e31b36d0095cc376da3e4
    - path: src/aief_exec/__init__.py
      digest: b8813ebc7fb18c820721517de771f9ed8ca224971824e2e9680f227ef5f77b69
    - path: src/aief_exec/__main__.py
      digest: 04d89d567dc1b3885024128e0d4cfb22a2e69f3083bfb69b332304dee6d32d96
    - path: src/aief_exec/checks.py
      digest: e5f5b1103e6bd26fd28da8c5560f83c215af3bb61e9e05c46beb53c31aa65610
    - path: src/aief_exec/graph.py
      digest: 0c9a596a11d5682e1c5dfd799b196d09c8d0f4934ffb5478c74b860e64524716
    - path: src/aief_exec/records.py
      digest: dd89352f92a0f9e46342e09ebbd5370122cdade00816fa227d575d54bc0583a7
    - path: src/aief_exec/scope.py
      digest: 816f2d98d73be840cb3aad4a374eb7ee9c369f9bb449eae8c100dbead32d9b2a
    - path: tests/test_exec_admission.py
      digest: 85166a54ed18928111d34f86e24563f91ea865def2f98e99b9c21650d896a996
    - path: tests/test_exec_checks.py
      digest: d254cab0cc3004d9a8c64901f1a5fe301c10ec8772165a1af4dbc347db3c393b
    - path: tests/test_exec_graph.py
      digest: 256dca6656d6c470c389e8330277e4d18810bb3e7dca5dbf6cd5c615b8acdf39
    - path: tests/test_exec_records.py
      digest: 0ef2142ee16aecbbc92bed994f03716d70dba5b5cc82255d94bca61d1ccbcfc2
    - path: tests/test_exec_scope.py
      digest: 8246e8ff39536819a1cb3e167d219f4d4109b2c6ccf9d5e003853ce3cef15b38
    - path: tests/test_exec_supersession.py
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

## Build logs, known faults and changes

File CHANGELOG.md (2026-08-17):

# Changelog

All notable changes to this repository are recorded here.
Format follows [Keep a Changelog](https://keepachangelog.com/en/1.1.0/).
Versioning follows the release tag scheme in `releases/TAGS.md`.

---

## [Unreleased] — portfolio and governance closeout

> **No engineering artifact is created, modified or deleted.** `spec/**`, `cad/**`,
> `drawings/**`, `analysis/**`, `params/**`, `src/**`, `tests/**`, `framework/**` and
> `.ai/core/**` are untouched, and no Fusion document was opened. Sessions
> `S-2026-08-18-01`; no new release tag.

### Added
- **`docs/**` — the portfolio and presentation layer.** Recruiter overview, architecture,
  verification, failure-recovery, QA, release, deliverables, portfolio-asset register,
  documentation-findings register, interview material, résumé bullets, a post draft, and an
  architecture diagram. These carry **no authority**; where one appears to conflict with a
  canonical artifact, the canonical artifact governs.
- **`R-031`** — the lawful supersession of `R-030`, republishing the pinned `README.md` DC-1
  after the portfolio rewrite. `R-030` is preserved unedited but for its closing edit and is
  sealed at the DC-1 it now stands at, per `EXECUTION_ARCHITECTURE.md` §6.1.

### Changed
- **`README.md` rewritten** for a reader who does not know AIEF, with the physical-qualification
  boundary and `ECR-D-016` on the first screen rather than in an appendix.

### Fixed
- **`README.md` published a clean-clone figure of "821 passed, 52 skipped"** — a total of 873
  that predates the 22 tests round 5 added. Measured **843 passed, 52 skipped, 0 failed** from
  a clone of `origin` at `f8ff028`; **894 passed, 1 skipped** with the tokenizer artifacts
  provisioned; **895 passed** in the working tree. This entry's own §[0.11.0] and
  `RELEASE_READINESS_v0.11.0.md` §2 already published 843, so the README was the outlier.
- **`README.md` published `ECR-D-014` as OPEN.** It is CLOSED — `OPEN_ITEMS.md` governs.
- **`ENGINEERING.md` §1 named `v0.10.0` as the last tag** after `v0.11.0` was applied. The row
  had cured the *distance*, which stales on every commit, and left the *name*, which stales on
  every release.
- **`RELEASE_READINESS_v0.11.0.md` disagreed with itself about which release it audits.** §1
  cited `1c15818` and 800 tests while §2 cited 843; §2's PII row cited 583 tracked files
  against 597; §3 said three QA rounds while §5 tabulates five; §6 said 852 tests against 895.
  All corrected to the state at `f8ff028` with the superseded readings recorded in the header.
- **This entry's own lead said three QA rounds and `ECR-D-014` open.** Rounds four and five ran
  before the tag was applied. Corrected below.

### Known, and not fixed here
- **Repository visibility is `private` and no GitHub Release object exists** for any tag. Both
  are owner actions on GitHub that no file in this tree can perform.
- `docs/DOCUMENTATION_FINDINGS.md` carries the full register, including what this pass
  declined to repair and why.

---

## [0.11.0] — 2026-08-17 — Public release: CAD and software complete

> **Five independent cold-context QA rounds ran against this release.** Four returned
> `NOT CLEARED` and each found a real defect in a repair that looked complete; the third
> declared the `ECR-D-014` enforcement condition fully discharged after fifteen source
> mutations, and refused closure on record accuracy alone; the fourth found that the check
> written to end a recurring defect did not catch that defect. **`ECR-D-014` is CLOSED**, on
> the fifth round's own recommendation — a `qa-engineer` act in a distinct cold session, with
> LAW-05 satisfied because no session that repaired it certified its own repair, across four
> consecutive attempts. Every finding is recorded, and the corrections below are the result.
>
> *This lead read "Three independent cold-context QA rounds … `ECR-D-014` is left **open** …
> three times running" until `S-2026-08-18-01`. It was written after round three and never
> re-read against the release it describes; rounds four and five both ran before the tag was
> applied. The sections below are as written at their rounds and are left so.*

### Corrected after the second and third rounds
- The `ECR-D-014` ruling was enforced **only on the preview path**; a canonical build could
  have emitted a 249-token prefix against a cap of 200. `run()` now re-derives the measurement
  from the octets it emitted and halts on disagreement. **Fifteen mutations die.**
- `TCR-002` has **eight** findings, three BLOCKING — not six and two. `F-7` repaired, `F-6`
  and `F-8` carried.
- `ECR-D-015`'s byte-identity claim was false of the final state and its byte total was
  derived from the source rather than measured. Corrected at the ECR **and** at
  `cad/DELIVERABLES.md`, which had kept publishing the withdrawn claim.
- `README.md` claimed a reproducibility never tested from outside: a clone failed 35 tests.
  Now **843 passed, 52 skipped, 0 failed**, measured from a clone of the published repository.
- `LICENSE` §2's *"nothing in the set is copyleft"* was wrong — `certifi` is MPL-2.0. The
  conclusion survives on the correct ground: nothing is vendored, modified or redistributed.
- `STATE_REGISTER.md` recited three values that its own session's close moved, three sessions
  running. **Cured procedurally**: the recitals are removed and
  `tests/test_state_register_currency.py` fails if any governed value it states goes stale.
- **`OI-C-10` arrived.** Raising one more open item took the bounded index to 602 tokens
  against its 600 cap and halted `V-09`. The identifier was withdrawn and the finding folded,
  recorded at both rows as forced by the budget rather than by the merits. **No session-level
  action remains**; the next distinct finding cannot be folded.

**The repository becomes public.** Every CAD-verifiable property is verified and reproducible
from a clean clone; **nothing physical has been built or measured**, and one defect is open
against the design itself. Session `S-2026-08-17-01`; decisions at
`.ai/project/decisions/DECISIONS_S-2026-08-17-01.md`.

### Added
- **`LICENSE`, resolved — `MIT AND CC-BY-4.0`, boundary by path** (closes **`C-4`**, DEC-11).
  Code MIT; documents, engineering artifacts and generated design data CC-BY-4.0. Full MIT text
  and the full CC BY 4.0 legal code embedded verbatim so the licence survives without a network.
  §3 states expressly that **no patent and no trademark licence is granted**, and that the
  design is not qualified hardware. Third-party licences were read from each installed
  distribution's own metadata, never assumed; nothing in the set is copyleft. No per-file
  header is used or permitted — one would move a registered DC-1 digest and halt boot step B2a.
- **The CAD deliverables are in the repository** (**`ECR-D-015`**, DEC-12): 61 files mirrored in
  byte-identically to `cad/exports/`, `cad/bom/` and `drawings/`. Previously a clone contained a
  register of 62 digests naming files on one machine. Byte identity proven by SHA-256 before and
  after and again through a clean `git checkout-index`.
- `python -m aief_deliverables` — bi-directional standing check binding the register to the
  tree, with 12 adversarial tests.
- `python -m aief_analysis` — the two `OI-C-15` desk analyses, computed and tested (16 tests).
- `.ai/project/STATE_REGISTER.md` — declared in the frozen manifest since 2026-08-08 and never
  written (`OI-V-13` FIND-3; `TCR-002` F-2, filed BLOCKING eight days earlier and unactioned).
- `requirements.txt`, with each dependency's licence recorded beside it.
- `tests/test_stage6_prefix_enforcement.py` — pins the `ECR-D-014` ruling **at the pipeline**,
  not at the function. 47 tests added overall; suite 799 → 895.

### Fixed
- **`V-03` enforced half its declared domain and reported green.** The state register pair was
  skipped by a branch that sat *before* the existence test, so a declared register could be
  absent while `V-03` passed. Both pairs are now checked; `register_pairs` 1 → 2.
- **The `ECR-D-014` ruling was enforced by nothing.** Three call-site mutations — measuring the
  whole document instead of the boot-read prefix, substituting the cap, skipping the check and
  fabricating `PASS` — each survived all 799 tests. Each was applied for real and confirmed
  caught. (`OI-V-13` FIND-1, BLOCKING.)
- **`ECR-D-014` §4 stated as fact something the repository contradicts.** The defect was
  measured and escalated BLOCKING two days earlier by an independent cold session (`TCR-002`
  F-3) that this record cited nowhere. Corrected in place, priority claim withdrawn, and
  `TCR-002`'s **eight** findings — three of them BLOCKING — now carried at `OI-V-14`. (FIND-2;
  the count itself corrected from six after round 3 found this line uncorrected.)
- Two silent swallows in the approval-chain parser: a repeated `subject_path` let a good binding
  mask a fabricated one, and a block-sequence `prior_hash` was read as null and silently rooted
  the chain. (FIND-8.)
- `boot_read_prefix` matched a substring where the ruling specifies a member line. (FIND-7.)
- Drawing PDFs are now **byte-deterministic**: matplotlib's wall-clock stamp made every PDF
  differ on every render. Proven over two consecutive renders, 39/39 stable.
- `ENGINEERING.md` §8 told readers to expect two failures a repaired repository does not produce
  (FIND-9); `GATES.md` recited an index section two of its four ids had left (FIND-10,
  `ECR-Q-015`, re-bound by `APR-038` after the edit correctly voided `APR-028`).
- `cad/DELIVERABLES.md`, the BOM builder and `final_system_verification.py` all pointed at an
  external output root; all now read the repository.
- `SEWCP-401` material was specified two ways — `spec/03` §5.2 governs, 316L (**`ECR-Q-014`**).

### Changed
- `framework.manifest.json`: `metadata.license` resolved and two `authority` fields amended by
  `AIEF-AMD-015` now cite it (**`ECR-D-017`**, `APR-037`). Three leaves, zero removals, proven
  by structural diff. Registry re-registered; DC-2 → `1f32489a…8d45cc4b`; Stage 6 re-emitted so
  the lock's `source_manifest_dc1` names the artifact that exists. **DC-4 and
  `BINDING.core_digest_pin` did not move**; B2a re-verified independently at 75/75.
- `.gitattributes`: the four deliverable subtrees are `-text`. The blanket `* text eol=lf` would
  have corrupted 24 binary deliverables and moved every recorded digest — the check that file's
  own comment demanded before adding binary content.

### Engineering findings
- **`ECR-D-016` — the Support Ring isolation joint does not close.** `SR-02` (353.9 Ω vs 400),
  `SR-03` (14.00 mm vs 20) and `SR-04` (≤ 8.50 mm vs 12) all fail on frozen dimensions, for one
  reason: `spec/03` §2.1 and §3.1 compute the flange gap as empty while §5.2 puts a 6.00 mm
  grounded ring inside it. Proven against the specification's own published answer. Ruled
  **disposition A — Rev B baseline revision**, with a feasible Rev B computed and published;
  **implemented at Rev B, not here.** **Blocks hardware build. Blocks no gate and no release.**
- `OI-CAD-04` — four dimensioned `SEWCP-400` features, three marked *Critical*, are absent from
  the verified model. Not a modelling slip: they have no radial room to exist in, which is
  `ECR-D-016` §2.3.
- `SR-07`/`AP-08` re-run at the as-modelled 7.69973 kg (+2.66 %): **both discharge**, and the
  governing case does not reach SF = 3 until 84.4 kg, so no unmodelled BOM line can disturb it.

### Verification
- **Independent cold-context QA (`OI-V-13`) returned `NOT CLEARED`**, with 17 findings. It
  **cleared `ECR-D-006`** — every element reproduced, and it confirmed the recorded residual more
  strongly than the record had — and **refused `ECR-D-014`**. Both grounds are now repaired, and
  **this session may not certify its own repair**: LAW-05 bars it and no delegation of owner
  authority reaches a constitutional separation. `ECR-D-014` stays open awaiting one fresh round.

### Known limitations
- **0 of 91 hardware-verifiable requirements are verified. No article exists.**
- `ECR-D-016` blocks hardware build pending a Rev B baseline revision.
- `CMP-BLOCK-004`/`-005` remain open; they gate **AIEF framework Release 1.0.0**, not this
  repository's release (DEC-18).

---

## [0.1.0] — 2026-08-07 — Infrastructure Baseline

Repository infrastructure only. **No engineering content was created, modified, reviewed, or decided in this release.**

### Added
- Git repository initialised on branch `main`.
- `.gitignore` covering Autodesk Fusion 360, Python, VS Code, OS artefacts and CAE scratch.
- `LICENSE` placeholder — **unresolved, blocks public release**.
- `CONTRIBUTING.md` placeholder carrying the binding repository policy (P-1 … P-5).
- `CHANGELOG.md` (this file).
- `INDEX.md` — master document index.
- Root `README.md` — repository landing page.
- `implementation/` with nine component folders, each containing `cad/`, `params/`, `drawings/`, `verification/` and a placeholder README.
- `releases/` with `TAGS.md` tag scheme and the `v0.1/` manifest.
- `cad/fusion/` and `cad/archive/`.
- `traceability/DOCUMENT_DEPENDENCY_MAP.md`.
- `traceability/DOCUMENT_TRACEABILITY_MATRIX.md`.
- `releases/v0.1/RELEASE_0.1_READINESS_REPORT.md`.
- `.gitkeep` markers in otherwise-empty tracked directories.

### Moved
- `docs/` → `spec/` (11 files). **Content unchanged, byte-for-byte.** Aligns the repository with the structure ratified in SEDEP-PMP-002 §1 and closes the open item raised at program plan issue.
- `cad/SEWCP-200_CAD_Implementation_Package.md` → `implementation/01_SEWCP-200_Cooling_Plate/`. **Content unchanged.**

### Removed
- Empty `docs/` directory after migration.

### Notes
- The engineering baseline `spec/` (SEWCP Rev A, Volumes 00–09) is **FROZEN** and was not altered.
- Four open **ECR-D** defects recorded against the frozen baseline in `implementation/01_SEWCP-200_Cooling_Plate/SEWCP-200_CAD_Implementation_Package.md` §12. These block engineering release, **not** this infrastructure release. See `releases/v0.1/RELEASE_0.1_READINESS_REPORT.md`.

### Unresolved at Release 0.1
| ID | Item | Blocks |
|---|---|---|
| C-4 | `LICENSE` placeholder not resolved | Public / external release |
| C-5 | CI workflows not populated | Automated verification |
| ECR-D-001…004 | Baseline defects (engineering, pre-existing) | CAD modelling of SEWCP-200 |

---

[Unreleased]: ./
[0.1.0]: ./releases/v0.1/

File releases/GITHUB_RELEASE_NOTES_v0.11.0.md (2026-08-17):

# GitHub Release notes — `v0.11.0` (PREPARED, NOT PUBLISHED)

> **Instance artifact.** Partition `releases`. Owner `repository-engineer`.
>
> **Publication is gated and this file does not release anything.** At the time of writing, the
> repository is **private** and **no GitHub Release object exists for any tag**
> (`gh api repos/…/releases` → `0`). Creating a Release page and changing visibility are both
> owner actions on GitHub that no file in this tree can perform.
>
> The tag `v0.11.0` **is** pushed and its annotation already states the physical-qualification
> boundary and `ECR-D-016`. The body below is prepared so that publication, if the owner chooses
> it, is a paste rather than a rewrite — and so that the release page cannot say something the
> repository does not support.
>
> **Prerequisite before publishing:** the safety audit at
> [`../docs/DOCUMENTATION_FINDINGS.md`](../docs/DOCUMENTATION_FINDINGS.md) must have no
> unresolved finding, and the repository must be public — a Release page on a private repository
> is visible to no one and creates the impression of publication without it.

---

## Release title

    v0.11.0 — CAD and software complete; physical qualification not started

## Release body

<!-- everything below this line is the intended Release body, verbatim -->

**An agent-driven engineering pipeline that converts governed semiconductor-equipment
requirements into parametric Fusion 360 designs, verifies the resulting geometry against the
requirement from the model Fusion actually built, and iterates through failure-recovery loops
before release.**

Demonstration hardware: **SEWCP**, a 300 mm bipolar electrostatic chuck pedestal for RF-biased
plasma process equipment.

### Read this first

This release is a **design and process artifact, not a qualified product.**

- **Nothing physical has been built or measured.** 0 of 91 hardware-verifiable requirements are
  verified. Four mass figures are labelled `MODEL-PREDICTED`; the declared method is a scale, and
  a scale needs a part.
- **One defect is open against the design itself.** `ECR-D-016` — the Support Ring isolation joint
  does not close: creepage 14.00 mm against 20.00 mm required, clearance 8.50 against 12.00, shunt
  impedance 353.94 Ω against 400. It is ruled, its remedy is computed, and it is deliberately not
  implemented, because implementing it is a specification re-baseline. **Do not build to this
  baseline.**

### What is in the release

| | |
|---|---|
| Components specified, frozen Rev A | **9** — 137 numbered requirements |
| Part designs modelled and verified | **10**, plus a **19-occurrence** master assembly, 7.6997 kg |
| Final system verification | **19 / 19** · system interfaces **12 / 12** |
| Drawings | **11 documents / 14 sheets** — 79 dimensions, **0 unsourced** |
| Deliverables | **61 files**, 4,995,097 bytes, digest-registered and checked both directions |
| Tests | **895** in the working tree · **843 passed, 52 skipped, 0 failed** from a clean clone |
| Independent QA | **5 cold-context rounds**, 4 returned `NOT CLEARED` |
| Tracked CAD runs | **36 — 18 PASS and 18 FAIL**, failures committed on purpose |

### The idea

> A CAD operation succeeding is not evidence that it worked.

`extrude(...)` returning OK means Fusion accepted the operation. Three facts are kept apart and
never merged: an agent **requested** an operation; Fusion **performed** it; the model **satisfies**
the requirement. Only the third is acceptance, and it is decided by verifiers that read observed
model state — extents, volume, mass, material, parameters, sketches, planes, features — and never
read whether the call returned OK.

Worked example, from the tracked record: two Ø6 hanger taps, eight operations dispatched, eight
executed, zero Fusion errors. The run **failed** — the observed solid carried **173.71 mm³** more
material than the requirement allowed against a **1 mm³** tolerance. Root cause was not the model
but the specification: no compliant tap position existed anywhere inside the placement window the
requirement gave.

### Verification and its boundary

Every CAD-verifiable property is computed from observed evidence and reproduces from a clean
clone. Two standing checks exit non-zero **and are meant to** — `aief_analysis`, because
`ECR-D-016` does not close, and `aief_exec check`, which reports three open exec-layer conditions
of its own. A check reporting PASS on an open defect would itself be the defect.

**CAD/software verification is not physical qualification.** A model establishes geometry and the
properties that follow from geometry and a density. It establishes nothing about pressure drop,
heat transfer coefficient, leak rate, temperature uniformity, contact resistance, inductance,
particle generation, outgassing, cycle life, dielectric strength or dechuck behaviour.

### Known open

- `ECR-D-016` — blocks hardware build; Rev B baseline revision required.
- `PVR-001` — 0 of 91 hardware-verifiable requirements verified.
- `OI-V-17` — four consecutive repair sessions each introduced a defect of the class they were
  repairing. A process finding, recorded and not closed.
- `CMP-BLOCK-004` / `-005` — gate **AIEF framework** Release 1.0.0, a different release of a
  different thing.

Full register: [`.ai/project/OPEN_ITEMS.md`](../.ai/project/OPEN_ITEMS.md).

### Licence

`MIT AND CC-BY-4.0`, boundary by path — MIT for software, CC-BY-4.0 for documents, engineering
artifacts and generated design data. **No patent and no trademark licence is granted, and the
design is not qualified hardware.** See [`LICENSE`](../LICENSE), which is authoritative.

<!-- end of intended Release body -->

---

## Publication checklist — owner

1. [ ] Repository visibility set to **public** (or a deliberate decision that it stays private,
       in which case **do not** create a Release page).
2. [ ] `docs/DOCUMENTATION_FINDINGS.md` carries no unresolved security or licensing finding.
3. [ ] `main` carries the governance closeout and the `validate` workflow is green on it.
4. [ ] Release created against the **existing** annotated tag `v0.11.0` — the tag is never
       moved, per `TAGS.md` §4 rule 2.
5. [ ] Release marked as **not a pre-release**; the digital release is complete on its own terms.
6. [ ] No binary attached beyond what the repository already tracks. The 61 deliverables are in
       the tree and digest-registered; a second copy on a release page is a second thing to keep
       in agreement.

**Nothing in this file authorises step 1.** That transition is the owner's.

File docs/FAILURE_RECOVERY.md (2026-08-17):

# Failure → Recovery → Verification

*Two real failures from the tracked record. No example here is invented; every figure is quoted
from a file in this repository, and each file is named.*

The repository tracks **36 component CAD runs — 18 PASS and 18 FAIL**. The failures are
committed on purpose. A design system whose record contains only successes has not shown you its
verification working; it has shown you its verification never firing.

---

## Case 1 — The two taps that Fusion built perfectly, and that were wrong

**The one that justifies the whole architecture.** Every CAD operation succeeded. Nothing errored.
The part was wrong, and the only thing that noticed was a number read back out of the model.

### Initial design and action

`ECR-Q-012` ruled a plate-hung RF hanger, which required two new M6 × 12 bracket taps in the
Cooling Plate's bottom face. The specification's own interface requirement **`RF-IF-3` gave a
literal placement window: "Ø274 BC ± 40 mm"**. The design agent placed the taps by that literal
reading — **r = 137 mm, at 88.27° and 121.73°** — and the placement was reviewed and approved
(`APR-029`).

Run `RUN-20260811T224345-ff189f` dispatched eight operations:

```
new_document · set_parameters · rename_component
create_sketch  S6_HANGER_TAP
sketch_circle  centre (  4.132869, 136.937648)  Ø6.0     ← r = 137.0000, θ =  88.2713°
sketch_circle  centre (-72.047994, 116.525047)  Ø6.0     ← r = 137.0000, θ = 121.7287°
extrude        cut, 12.0 mm
observe
```

### Observed failure

```
dispatched: 8   executed: 8   execution_halt: null
```

**Fusion executed all eight and reported no error.** A pipeline that trusts command success ships
this part.

The verifier read the model back and returned `FAIL`, 9 checks, 1 failed:

| | |
|---|---|
| `id` | `ACC-VOL` |
| `subject` | `body:CP_BODY.volume_mm3` |
| `requirement` | `CP-HANGER-TAP` |
| `expected` | `1479108.9` |
| `observed` | `1479282.6100163697` |
| `detail` | `delta 173.71 exceeds tolerance 1` |

A discrepancy of **0.012 %** of the part volume, caught against a **1 mm³** tolerance on a
1.48 × 10⁶ mm³ solid.

### Root-cause classification

`_classify` maps subject `body:*` to *"the solid was not created, or its extent does not match the
distance the solution declares"* → **repairable, re-dispatch the profile and extrude operations.**
So the loop tried.

- Attempt 2: a 5-operation repair sequence, digest `sha256:fc10713e…`
- Attempt 3: the same repair, same digest, same finding
- Escalation recorded: `attempt limit 3 reached with 1 check(s) still failing`

**The loop stopped rather than degrading into a pass.** That is the second guarantee in
`loop.py` — *"On exhaustion the loop stops and reports the surviving findings, which is a real
outcome; it does not degrade into a pass."*

### Owning layer — and this is the interesting part

Re-dispatch could never have fixed it, because **the defect was not in the CAD layer at all.**

The engineering diagnosis, recorded at `DEC-02 addendum`: the taps at r = 137 **intersect the
90°/120° outer choke through-slots** (Ø270 BC, 5.5 × 7.0). Two blind M6 × 12 taps should have
removed **678.6 mm³**; because they broke into existing voids they removed only **504.8 mm³** —
and 678.6 − 504.8 = **173.8 mm³**, which is the delta `ACC-VOL` reported.

A feasibility sweep was then run across the whole approved window:

> *"the slot at 90° and the land edge at 93° close the lower window; 117°–120° closes the upper
> one — **no compliant position exists inside ±40 mm**. RF-IF-3's window is itself infeasible;
> nothing at Ø274 BC was ever clearance-checked for bracket taps."*

**The requirement was wrong, not the model.** The owning layer was the specification.

### Rollback

Before anything else, the failure disposition ran. The run record shows it attempting
`discard_document` and being **refused by contract**:

```
discard_document: 'SEWCP-200_COOLING_PLATE' is persisted;
a saved design is never discarded by recovery - use revert_document
```

That refusal is the document-lifecycle policy firing in production: *an authoritative design can
never be destroyed by a failure path.* It fell back to `revert_document`, which restored the
previously verified plate automatically (`DEC-02 addendum`; `cad/POST_GEOMETRY_RUN.md`). Across
all three attempts the failing document was **never saved** — `saved: false` throughout.

### Repair

Corrected placement **r = 150 mm, at 88° and 122°**, and — because the first placement had been
approved on an unchecked window — the new one was cleared against nine named neighbours before
it was dispatched: choke slots (15.8 mm centre distance against 8.4 needed), ring bolts at
112.5°/67.5° (24.9 mm), locator slots (74 mm), land outer radius 146 against tap inner edge 147,
channel envelope (125), RTD ports, coolant stubs, plate OD (foot edge 159 < 160), and the
top-face ring taps. Both specification rows were re-issued under `APR-031`/`APR-032`.

### Re-execution and independent verification

Run `RUN-20260811T224915-001c51` — a **different requirement package and a different design
solution**, which the record proves: `package_digest` and `solution_digest` both differ from the
failed run's. The correction was made in the layer that owned it.

```
sketch_circle  centre (  5.234925, 149.908624)  ← r = 150.0000, θ =  88.0000°
sketch_circle  centre (-79.48789,  127.207214)  ← r = 150.0000, θ = 122.0000°
```

| | |
|---|---|
| Verdict | **PASS**, attempt 1, 9 checks, 0 failed |
| `ACC-VOL` | expected `1479108.9` · observed `1479108.8648750156` — **within 0.04 mm³** |
| `saved` | `true`, version 1 — the first and only save, on verified PASS |

Elapsed between the failed run finishing and the corrected run starting: **5 min 13 s**.

### Why this matters in engineering

Two M6 taps breaking into the outer choke slots is not a cosmetic defect on a plasma pedestal.
The choke slots carry the thermal isolation between the heater and the cooling plate; a tap
opening into them puts a fastener path into a thermal break, on a bottom face that is masked
from anodising and sits in the RF return. It would have been found at first article, or at
first thermal characterisation, or later.

It was found in **seventeen seconds** of run time, by comparing a volume against a requirement.

---

## Case 2 — The empty document that could have reported green

**The failure mode this repository is most organised against: a check that cannot be evaluated
being counted as a check that passed.**

### Initial action

Run `RUN-20260811T183336-a70c01` — Support Ring `SEWCP-400`, alumina, 26 acceptance checks.

### Observed failure

```
attempt 1  execution_halt:
  OP-0004 (assign_material) did not execute -
  RuntimeError: no material matching 'Aluminum Oxide' in any loaded library
```

Fusion accepted operations 1–3 and then refused the fourth: the material name in the solution
did not exist in any loaded Fusion material library. The sequence halted, leaving a document with
**0 bodies, 0 parameters and no planes**.

The verifier scored it **22 of 26 failing** — and the interesting thing is *how* it reported the
misses:

```
ACC-BODY-DZ    body:SR_BODY.dz      expected 20.3   observed None
   "not present in the observed model. A check that cannot be evaluated has not passed"

GEO-BODY-PRESENT   bodies.count      expected >= 1   observed 0
   "the solution extrudes a solid but the model reports no body"

IF-PLANE-...       plane:PL_WEB.exists   expected True   observed False
   "construction plane 'PL_WEB' is declared by the solution and absent from the model;
    every feature that locates against it is unlocated"

GEO-PATH-OBSERVED-mech.SR-BFLANGE.rings   sketch:G1_BFL.curve_geometry
   "the routed path cannot be verified without observed curve geometry;
    unmeasured is not compliant"
```

This is `observe.py`'s rule — *absence is represented as absence* — doing the work. Had a missing
body been modelled as a body of volume zero, several numeric checks would have compared 0 to 0
and passed on an empty document.

### Root cause, owning layer, and the bounded repair

Attempts 2 and 3 got past the material and halted further down:
`RuntimeError: sketch 'G1_BFL' yields no closed profile` — a second, independent defect in the
sketch construction, uncovered only because the first was cleared. Failing checks rose to 24 of
26 as more of the sequence executed and more of the model could be checked at all. Escalation:
`attempt limit 3 reached with 24 check(s) still failing`.

Both causes sat in the operation-compilation layer: a material identifier that did not resolve
against Fusion's libraries, and a profile that did not close. Neither is an engineering
escalation, and neither was guessed at — `document.units` and unclassified findings are the two
categories `_classify` refuses to repair, on the stated principle that *"an unclassified failure
is not repaired by guessing."*

### Re-execution and verification

Run `RUN-20260811T183556-788260` — **PASS**. `SEWCP-400_SUPPORT_RING` is in the released set:
STEP, STL, drawing `SEWCP-400-DRW-001`, and BOM line `Al2O3 99.5%`.

---

## The same pattern at three other layers

| Layer | Failure | How it surfaced | Outcome |
|---|---|---|---|
| **Acceptance criteria** | `SEWCP-901` RF strap failed `ACC-BODY-DX` (expected 131.25, observed 131.5) and `ACC-BODY-DZ` (expected 66.438, observed 66.68821) over three attempts | the *criteria* were stale, not the geometry (`cad/DOCUMENT_LIFECYCLE.md` classifies `RUN-20260811T200134-c51fe2` as "verdict FAIL — stale acceptance extents") | criteria re-derived; `RUN-20260811T200254-ca7080` PASS |
| **Architecture** | failed runs were leaving **saved blank Fusion documents** behind | `rename_component` had to `saveAs`, because Fusion refuses to rename an unsaved root component — so persistence preceded geometry, and no failure path disposed of the document | identity bound as a design attribute without persisting; first-save moved into `save_document` alone, dispatched only on verified PASS; enforced by `tests/test_document_lifecycle.py::test_only_the_verified_save_path_may_first_save`. Orphans deleted, not renamed — *"quarantine is not cleanup"* |
| **Escalation, correctly refusing to retry** | `SEWCP-1000` retainer: `ACC-FEATURES` expected 6, observed 5 | the loop declined to re-dispatch at all: `no repairable finding: every failure is an engineering escalation, not a re-dispatch` | escalated on attempt 1; corrected run `RUN-20260811T182006-72bc80` PASS |

---

## What the system is actually built to do

Not *generate CAD commands that succeed*. Any competent LLM can do that, and Fusion will execute
them.

**Discover that a command which succeeded produced the wrong engineering outcome — then say
which layer owns the mistake.** In Case 1 that layer was the frozen specification, and the
evidence that convicted it was 173.71 mm³ of aluminium that should not have been there.

Related: the same discipline applied to the framework's own software produced five independent QA
rounds and four `NOT CLEARED` verdicts — [`QA.md`](QA.md).

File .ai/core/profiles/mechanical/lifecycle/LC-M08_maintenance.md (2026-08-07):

# LC-M08 - Maintenance

> **Generated artifact.** Emitted by aief-compile Stage 1 from `framework.manifest.json`.
> Do not edit. Regenerate from the manifest.

| | |
|---|---|
| Framework | AIEF 1.0.0 |
| File id | `mech-lc-08` |
| Layer / partition | L3 / profile |
| Tier | T2 |
| Owner | `project-manager` |
| Mutability | immutable |

---

| Stage | 8 of 10 |
| Profile | `mechanical` |
| Gate | **terminal** |
| Predecessor | LC-M07 |
| Successor | LC-M09 |

## Gate

This stage exits through a **terminal** gate governed by `../../../laws/LAW-03_release_gates.md`.

Gate criteria for this project are declared in `project/GATES.md`, owned by `project-manager`. Criteria are binary and evidence-based; disposition is pass or fail.

## Permitted agents

Universal registry per `../../../agents/INDEX.md`, plus profile roles declared in `../PROFILE.md`.

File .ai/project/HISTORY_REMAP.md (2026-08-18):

# History Remap — the `ECR-D-018` publication-safety sanitization

> **Instance artifact.** Partition `project`. Owner `repository-engineer`. Mutability append-only in effect: rows are added when history is rewritten and never edited afterwards.
> **Authority:** [`ecr/ECR-D-018`](ecr/ECR-D-018_Local_Account_Name_Becomes_New_Public_Information_At_Publication.md), ruled at [`decisions/DECISIONS_S-2026-08-18-02.md`](decisions/DECISIONS_S-2026-08-18-02.md) DEC-22/23/24, override recorded at [`approvals/APR-039`](approvals/APR-039_Rank-1_Override_LAW-07_For_ECR-D-018_Sanitization.md).

---

**This file is the resolver for every commit hash written before `2026-08-18`.** A citation
elsewhere in this repository naming a pre-rewrite hash is **not stale and must not be edited**:
it correctly names the object that carried the statement when the statement was made. Resolve
it here.

## 1 · What the rewrite changed, and what it did not

**Changed:** the local Windows account-name segment of a filesystem path, replaced by the
neutral placeholder `<user>`, in **53** occurrences across **11** blobs — the ten
`cad/runs/RUN-*/run.json` failure records and the `DEC-21` text in
`decisions/DECISIONS_S-2026-08-17-01.md`.

**Not changed, and measured rather than asserted** (see [`results/R-032.md`](results/R-032.md)):
author identity, committer identity, author and committer timestamps, commit messages, tag
annotations with their tagger and date, file modes, path names, and every other byte of every
file. Traceback structure, exception types, exception messages, module names, line numbers,
run ids, operation ids and Fusion build identifiers are all byte-identical. **No failure was
hidden, softened or deleted.**

## 2 · Commits that did **not** change

**29 of 54.** Everything before `2026-08-11` is untouched, which is why the approval-provenance
chain survives intact: `d07e931`, `655aa75`, `be75798` and `8546960` all keep their hashes, and
the `ECR-D-006` attribution and the `APR-002`/`-004`/`-005` subject recovery are unaffected.

Ten of the eleven annotated tags are likewise unmoved: `baseline/spec-revA`, `v0.1.0`,
`v0.3.0` … `v0.10.0` all resolve exactly as before.

## 3 · Commit remap — 25 rows, oldest first

| Pre-rewrite | Post-rewrite | Date | Subject |
|---|---|---|---|
| `7ba0b7545859` | `b71d5ad989e8` | 2026-08-11 | Build and verify the SEWCP-200 CAD increments through the agent-driven p |
| `9b28dd686682` | `c3933061c499` | 2026-08-11 | Design and build the SEWCP-200 below-face features through the agent pip |
| `038c4e5ce12e` | `7d02fae18aa9` | 2026-08-11 | Complete the SEWCP-200 CAD model: DR-6 vents, material, mass; automate t |
| `ac67ca824260` | `1c23fe6cbff4` | 2026-08-11 | Trim the STATE.md next-action block back inside its V-09 token cap |
| `45805b8d2fea` | `8d9751af5960` | 2026-08-11 | Build and verify SEWCP-700 through the autonomous loop; export deliverab |
| `6f3f973880ab` | `9fe8232b8b13` | 2026-08-11 | Hold STATE.md inside its V-09 cap after the SEWCP-700 status update |
| `df77294bb324` | `f400685d317d` | 2026-08-11 | Autonomous loop: SEWCP-600, SEWCP-1000 and SEWCP-800 designed, built, ve |
| `d5475845bbca` | `e10c2043ba91` | 2026-08-11 | Autonomous loop: SEWCP-901 strap and SEWCP-902 saddle built, verified, e |
| `d2cade97e163` | `6aaec3bf1935` | 2026-08-11 | Autonomous loop: SEWCP-400 support ring built, verified, exported |
| `3889a48e806b` | `97d6b4459a52` | 2026-08-11 | Spiral routing for the heater grooves: exact keep-out projection, arc-ch |
| `4d03041d4a9b` | `04c016be81ce` | 2026-08-11 | Complete the defined SEWCP CAD design: all nine component volumes verifi |
| `fc2a336b3a3a` | `cbee971cdb79` | 2026-08-11 | Post-geometry completion: assembly built and verified, drawing set, BOM, |
| `1c07cf882a37` | `b36591e4ab79` | 2026-08-11 | Document-creation lifecycle repair: identity without persistence, save o |
| `7b743a9b54b7` | `efc1f4e50476` | 2026-08-11 | Bridge resumed: orphans deleted, lifecycle validated live, CP lineage re |
| `baf843a0edc7` | `1ab47aa4aa7d` | 2026-08-11 | Delegated-authority engineering resolution: ECR-D-013/Q-011/Q-012 and th |
| `8aa5b77e67a0` | `11122a3521af` | 2026-08-12 | Release-readiness audit: ECR-D-006 and ECR-D-014 dispositioned, five def |
| `2c334ae32c3e` | `e480aa58bf21` | 2026-08-12 | Stage 6 canonical closeout: B2a proven, OQ-14 closed, ledger genesis to  |
| `c55ecafaa823` | `700fb3db4f97` | 2026-08-17 | Public release preparation: licence ratified, deliverables brought into  |
| `1c1581884774` | `2f829c7c24c8` | 2026-08-17 | Second independent QA round: canonical-path enforcement repaired, four f |
| `6d403bf7982e` | `3b0a662e68ae` | 2026-08-17 | Third independent QA round: enforcement condition discharged, register s |
| `f3e3b7cfa16d` | `263f5f6fffb0` | 2026-08-17 | Fourth independent QA round: the check written to end a recurring defect |
| `f8ff028d56ae` | `cad6ced67c67` | 2026-08-17 | ECR-D-014 closed on the fifth independent round; register check rebuilt  |
| `3a0656d20076` | `de3f87e6a0e2` | 2026-08-18 | Add portfolio documentation set and rewrite README for a general reader |
| `4f20ef1b67d0` | `748c6c5be902` | 2026-08-18 | Supersede R-030 with R-031 and close the portfolio governance gap |
| `cf2163b3830b` | `ad50aebf1b20` | 2026-08-18 | Reopen DEC-21 and authorise the publication-safety history sanitization |

## 4 · Tag and ref remap

| Ref | Pre-rewrite | Post-rewrite |
|---|---|---|
| `refs/heads/main` | `f8ff028d56ae` | `cad6ced67c67` |
| `refs/heads/docs/portfolio-presentation-pass` | `cf2163b3830b` | *(advances with this session's close)* |
| `refs/tags/v0.11.0` — tag object | `055fee8299b5` | `abe7f0fbc0c1` |
| `refs/tags/v0.11.0` — target commit | `f8ff028d56ae` | `cad6ced67c67` |

**`v0.11.0` remains the engineering release `v0.11.0`.** No new version number is created: the
git object hashes moved, the release did not. The tag is still annotated; its tagger, its
timestamp and the entire annotation message are byte-identical, and only the `object` line
differs.

## 5 · Citations resolved by this table

Seven distinct pre-rewrite hashes are cited **40 times across 20 tracked files**. Every one of
them is a historical statement — *"measured at X"*, *"the baseline at X"*, *"verifiable in the
X → Y diff"* — and every one is **left exactly as written**, per the owner's instruction that
historical records are not rewritten to look current.

| Cited hash | Resolves to | Cited in |
|---|---|---|
| `f8ff028` | `cad6ced6` | `ledger/SEG-0000/L-0000007`, `results/R-031.md`, `sessions/S-2026-08-18-01.md`, `CHANGELOG.md`, `README.md`, `docs/DOCUMENTATION_FINDINGS.md`, `docs/README.md`, `docs/RECRUITER_OVERVIEW.md`, `docs/RELEASE.md`, `docs/VERIFICATION.md`, `releases/RELEASE_READINESS_v0.11.0.md` |
| `baf843a` | `1ab47aa4` | `ecr/ECR-D-017…`, `results/R-022.md`, `verification/PVR-001…`, `releases/RELEASE_READINESS_S-2026-08-11-06.md` |
| `1c15818` | `2f829c7c` | `CHANGELOG.md`, `LICENSE`, `docs/DOCUMENTATION_FINDINGS.md`, `releases/RELEASE_READINESS_v0.11.0.md` |
| `4d03041` | `04c016be` | `cad/DOCUMENT_LIFECYCLE.md`, `cad/POST_GEOMETRY_RUN.md` |
| `3889a48` | `97d6b445` | `drawings/defs/sewcp_drawings.py`, `drawings/parts/SEWCP-300/SEWCP-300-DRW-001.provenance.json` |
| `6d403bf` | `3b0a662e` | `LICENSE` |
| `f8ff028d56aee3004b5d41eb1a3d5c3e8f579270` | `cad6ced67c675611620519fc9986ba861703c315` | `docs/RELEASE.md` |

**`ledger/SEG-0000/L-0000007` is append-only and was not edited.** Its reference to `f8ff028`
resolves through this table, which is the whole reason this table exists.

## 6 · The remote has **not** been updated

`origin/main` still stands at the **pre-rewrite** `f8ff028`, and the remote-tracking refs in
this repository still point there, because that is the truth about the remote until a
force-update is performed. **The pre-rewrite objects therefore remain reachable in this local
clone** through `refs/remotes/origin/*`, and the account name is still present in them.

That is a correct and deliberate state, not a residue: nothing has been published, and the
divergence is exactly what the publication gate exists to close. A clean clone of the
publishable refs — `refs/heads/*` and `refs/tags/*` — contains **zero** occurrences.

The required force-update is stated at [`results/R-032.md`](results/R-032.md) and is
**reserved to the owner**. `APR-039` grants no authority to perform it.

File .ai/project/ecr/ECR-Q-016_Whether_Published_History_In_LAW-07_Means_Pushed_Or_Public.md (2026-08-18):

# ECR-Q-016 — `LAW-07` clause 6 forbids rewriting *published* history and the framework never says whether "published" means pushed or public

> **Instance artifact.** Partition `project`. Filed per `manifest.templates → tpl-ecr`, schema `core/schemas/SCH-ecr.schema.json`.
> Raised at `S-2026-08-18-02` while planning the `ECR-D-018` sanitization, because the answer
> determines whether that act needs an override at all. Filed under `LAW-12`: the ambiguity is
> **not** resolved by assumption.

```yaml
ecr_id:       ECR-Q-016
class:        Q                      # query - an undefined term in a BLOCKING law
raised_by:    repository-engineer · S-2026-08-18-02
status:       OPEN
disposition:  null                   # LAW-02 clause 3 - only the chief-systems-engineer rules
ruled_by:     null
ruled_at:     null
instrument:   null
approval:     null
affected_artifacts:
  - .ai/core/laws/LAW-07_git_configuration.md
  - .ai/core/validation/CHECKS.md
evidence:     "See the evidence section."
impact:       "See the impact section."
requested_action: "See the requested-action section."
raised_at:    2026-08-18T00:00:00Z
related:      ECR-D-018, LAW-07, V-22
```

## 1 · Class

**Q — query.** `LAW-07` clause 6 reads, in full:

> **6. Published history is never rewritten.**

`V-22`, severity **BLOCKING**, restates it as a checked property: *"…published history is not
rewritten…"*. Neither the law, nor `V-22`, nor `AIEF-FRZ-001`, nor any of the fifteen
amendments defines **published**. Two readings are available and they are not equivalent:

| Reading | "Published" means | Does it bind this repository today? |
|---|---|---|
| **Narrow** | made publicly visible | **No.** `STATE.md` records the repository as PRIVATE; the visibility gate is unclosed |
| **Broad** | pushed to any remote | **Yes.** `origin/main` is at `f8ff028` on a private GitHub remote |

## 2 · Evidence

```
$ git remote -v
origin  https://github.com/Raar1999/SEWCP_Master_Assembly.git (fetch/push)
$ git rev-parse origin/main
f8ff028d56aee3004b5d41eb1a3d5c3e8f579270
```

`STATE.md` `next_action`: *"TWO OWNER GATES, closable by no session: repository PRIVATE, no
GitHub Release object."* `ENGINEERING.md` §7 says `Repository | **PUBLIC.**`, which is a
separate defect recorded at `ECR-D-018` §2.3 — and which is itself evidence that the two
senses are being conflated in this repository's own prose.

## 3 · Impact — **none on the act, and that is why work proceeds**

Under the **narrow** reading, clause 6 does not bind and the `ECR-D-018` rewrite needs no
override. Under the **broad** reading it binds, and the owner's rank-1 live instruction of
`S-2026-08-18-02` overrides it, recorded at `APR-039` per `PRECEDENCE` §4 and `LAW-10`
clause 4.

**The outcome is invariant under both readings**, so `LAW-02` clause 1 applies — *"work
proceeds under the ruling"* — and this query blocks nothing. It is filed because the term is
undefined in a BLOCKING check and the next session to meet it should not have to re-derive
that the answer did not matter this time. It may matter next time.

## 4 · Requested action

Rule which sense clause 6 carries, and state it in the amendment that rules it. If the broad
sense is intended, `V-22`'s implementation — when one is written, `CMP-BLOCK-005` — needs a
declared notion of what makes history published, since a check cannot observe a remote's
visibility from the working tree alone.

Two secondary clauses were engaged by the same act and are recorded here for the same reason:

- **clause 7**, *"Tags are annotated and never moved"* — `v0.11.0` must be re-pointed at the
  rewritten commit. Its annotation, tagger and timestamp are preserved byte-for-byte; only the
  `object` line changes. Whether re-pointing under a rank-1 override is "moving" is the same
  species of question.
- **clause 8**, *"Force push is prohibited unless explicitly authorised by the framework"* —
  note **by the framework**, not by the owner. No push is performed by this session, so the
  clause is not yet reached; it will be reached at the publication gate.

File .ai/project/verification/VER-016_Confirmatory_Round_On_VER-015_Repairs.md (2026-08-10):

# VER-016 — Confirmatory round on the VER-015 repairs

> **Instance artifact.** Partition `project`. Independent verification under `LAW-05`.
> Confirmatory round on the repairs dispositioned in
> [`DR-004`](../reviews/DR-004_VER-015_Disposition.md) against
> [`VER-015`](VER-015_Independent_Verification_ECR-D-002_003_004_and_the_Coherence_Package.md).

```yaml
verification_id: VER-016
subject:         the repairs claimed in DR-004 against the VER-015 findings on the ECR-D-002, ECR-D-003 and ECR-D-004 dispositions and the LC-M04 specification coherence package, together with the C1-C7 instrument changes made to close VER-015 F-18, F-19 and the disclosed C6 hole
verifier_role:   qa-engineer
author_role:     chief-systems-engineer
law:             LAW-05 - the verifier authored none of the work under audit and obtained every figure below by executing the repository, not by reading a claim about it
status:          VERIFIED WITH FINDINGS - NOT CLEARED. 6 PASS, 4 FAIL
session:         S-2026-08-10-03
```

---

## 0 · Scope, method and the instant

**This round is not a re-run of `VER-015`.** Its arithmetic findings reproduced and are not in
question here. This round decides one thing: **are the claimed repairs real, and does anything
remain that should stop `LC-M04-EXIT`?**

**Measurement instant: `2026-08-10T05:39:53Z`**, repository at `HEAD = 7a36ff2`. The tree was
quiescent throughout; the instant is recorded regardless, per `AMD-42` — a property of a tree at
an instant is not a constant. Git state was not altered by this round and no file outside this
report was written.

**Method.** Every digest below was recomputed by an implementation of `DC-1` and `DC-2` written
for this round from the normative text in `AIEF-AMD-008` §AMD-16 and `FROZEN.md` §*Hash
constructions*, in the system temp directory, **without importing `src/aief_*`** — the point of
a confirmatory round is not to trust the instrument under audit. Adversarial trials W4, W5 and
W6 were run in throwaway **copies** of the repository in the system temp directory.

---

## W1 — F-08, the torque · **PASS**

**Both volumes now agree.** `spec/06` §4 Retention row (line 116) and §10 step 5 (line 246) read
**1.2 N·m**; `spec/01` §6 step 12 (line 182) and §10 step 3 (line 271) read **1.2 N·m**.

**No live 2.5 N·m locator torque survives in `spec/**`.** One `2.5 N·m` token remains, in
`spec/06`:116, inside an explicit historical clause — *"The former 2.5 N·m put an M4 A4-70 at
~114 % of yield"*. That is a record of the superseded value, not an instruction. The other
`2.5 N` hits in `spec/**` are all in `spec/09` and are spring **forces** (`7.5 ± 2.5 N`), not
torques.

**The change is bound.** Recomputed independently:

| Claim | Value | Verdict |
|---|---|---|
| `APR-027` exists | `.ai/project/approvals/APR-027_Alignment_Pin_torque_correction.md` | ✔ |
| `APR-027.prior_hash` = `APR-023.subject_hash` | both `da702fe05f41b1bac39c3ca507c090a7f7e7258ae18db38addb4d079d755edc6` | ✔ |
| `APR-027.subject_hash` = current DC-1 of `spec/06` | both `75cda88184e5ae50acd05fb86dfb61ffc6238219462e8854120c05f14d04f396` | ✔ |
| `FROZEN.md` registers that digest | line 44, same 64 characters | ✔ |

**The two recorded aggregates now agree — checked, because VER-015 found them disagreeing once.**
My own `DC-2` over the 29 registry rows (sorted by the UTF-8 octets of `<path>`, records
`<path> <SP> <digest> <LF>`, no header, no trailer):

```
recomputed  73911786c0795f20b5c5ea5b9ae4a9254d306abaccd9cc9ce54fc55a5d5bc3c2
FROZEN.md   73911786c0795f20b5c5ea5b9ae4a9254d306abaccd9cc9ce54fc55a5d5bc3c2   § Aggregate
STATE.md    73911786c0795f20b5c5ea5b9ae4a9254d306abaccd9cc9ce54fc55a5d5bc3c2   frozen_set_hash
```

All three identical at full length. No path is registered twice; no registered path is absent.

**Residuals recorded, not blocking (F-09, F-10 below).** `FROZEN.md` § *Registration history*
carries **no row** for the `APR-027` re-registration — the last `spec/06` row is
`0d2aa747… → da702fe0…` under `APR-023`. The event survives only as prose in § *Aggregate*.
Separately, `ECR-D-009` still points `approval:` at the **superseded** `APR-023`, never mentions
`APR-027`, and its §*Torque* paragraph still reads *"`spec/01` §6 step 12 and §10 step 3 both
carried the old value; **both are corrected**"* — the sentence whose enumeration made F-08
invisible, with the third site still unnamed. The specification is repaired; the record that
misled is not.

---

## W2 — F-22, the references · **FAIL**

Fourteen records under `.ai/project/ecr/`, both halves tested mechanically.

**The nine `spec/**`-bearing records pass both halves** — `ECR-D-001`, `-002`, `-003`, `-004`,
`-007`, `-008`, `-009`, `-010`, `-011`: `approval:` resolves and the named approval's `ecr:`
lists the ECR. That is what `DR-004` actually repaired.

**`ECR-D-006` is not a failure:** `approval: null` is correct for an `OPEN` record reserved to
the human owner.

**Four records fail the back-reference half, and one of those also fails the existence half.**

| Record | `approval:` | Path resolves | Named approval lists the ECR |
|---|---|---|---|
| `ECR-D-005` | `approvals/APR-001_…` | ✔ | ✘ — `APR-001` has no `ecr:` field |
| `ECR-Q-001` | `approvals/APR-002_…` | ✔ | ✘ — `APR-002` has no `ecr:` field |
| `ECR-Q-002` | `approvals/APR-002_…` | ✔ | ✘ — `APR-002` has no `ecr:` field |
| `ECR-Q-003` | `project/approvals/APR-004_…` | **✘** | ✘ — `APR-004` has no `ecr:` field |

`ECR-Q-003` uses a path grammar no other record uses. The other thirteen are relative to
`.ai/project/`; under that grammar this one resolves to `.ai/project/project/approvals/…`, and
`.ai/project/project/` **does not exist**. It is a surviving instance of exactly the F-22 class.

`APR-001` … `APR-013` — thirteen approvals — carry no `ecr:` field at all; the field enters the
convention at `APR-016`.

**`DR-004`'s claim is false as written.** *"All nine ECR records re-pointed at the filed
artifacts; every reference now resolves and every named approval lists the ECR"* — the first
clause is true, the second and third are true **only of those nine**. Five of fourteen records
fail one half or both. None is under `spec/**`, so `LC-M04-EXIT` is not gated on this; the
overstatement is the finding.

---

## W3 — F-05 and F-06 · **PASS**

**`ECR-D-007` §8/§9 now describe the geometry the specification implements.**

| Quantity | `ECR-D-007` §8/§9 | `spec/01` §3.1 (lines 104–111) | Agree |
|---|---|---|---|
| Locator keep-out radius | **8.5 mm** (5.0 + 3.5 wall) | **8.5 mm** | ✔ |
| Channel outer limit at Ø260 BC | **r ≤ 121.5** | **r ≤ 121.5** | ✔ |
| M4 tap-drill wall | **6.85 mm** | **6.85 mm** | ✔ |
| Wall to OD at Ø306 BC | **2.00 mm** (1.93 worst) | **2.00 mm** (1.93 worst) | ✔ |
| Counterbore | **Ø12.000 → Ø10.000** | `CP-D09`/`CP-D10` **Ø10.000** H7; `spec/06` `AP-D03` Ø10.000 h6 | ✔ |

The superseded Ø12 arithmetic (9.5 / r ≤ 120.5 / 7.85) is gone from the record.

**Action 3 is no longer claimed to have been split out.** §8 now rules it *"Rejected, and
**dispositioned here**"*; §9 closes with *"**No `ECR-D-012` was raised.**"* and explains that
splitting it out would have been the manoeuvre `C7` exists to prevent.

**No live claim that `ECR-D-012` exists remains.** Repository-wide, the identifier occurs in
exactly three places: `ECR-D-007`:203 as the explicit denial, and `DR-004`:41 and `VER-015` as
the record of the finding itself. No record file, no index entry, no register row.

---

## W4 — F-18, the C7 evasion · **PASS**

**The attack was re-run, not read about.** In a temp copy I filed
`ECR-D-099`, `status: OPEN`, `disposition: null`, `affected_artifacts: [spec/01_SEWCP-200_Cooling_Plate.md]`,
and deliberately left `OPEN_ITEMS.md` untouched (verified: zero occurrences). Under `VER-015`
this passed. Now:

```
C7  FAIL   No ECR against the frozen spec remains undispositioned
    ! ECR-D-099: UNDISPOSITIONED against ['spec/01_SEWCP-200_Cooling_Plate.md'] …;
      listed in OPEN_ITEMS Blocking: False
    ! ECR-D-099: undispositioned but absent from OPEN_ITEMS.md Blocking -
      the index does not describe the records it indexes
```

The predicate now reads the records on disk and reports the index divergence separately. **The
hole is genuinely closed.**

**The converse also holds.** Adding `ECR-D-098` to `OPEN_ITEMS.md` § *Blocking* with no record
on disk:

```
C7  FAIL   ! ECR-D-098: listed Blocking with no record - C7 is undecidable
```

Reported, not ignored.

**One defect in the repair (F-11 below).** `C7`'s three evidence lines are unconditional prose,
emitted even when the residue contradicts them. In the trial above the checker printed *"10 bear
on `spec/**`; **all carry a non-empty disposition**"* and *"`OPEN_ITEMS.md` Blocking holds 4 ids
and **is consistent with them**"* in the same breath as the two residues proving neither was
true. The verdict is correct; the evidence text is false. A reader who skims evidence and not
residue is misled by the instrument.

---

## W5 — F-19, the thin-approval hole · **PASS**

In a temp copy I appended one comment byte to `spec/README.md` and filed **no** superseding
approval. That is the thin instrument `VER-015` showed `C2` had been resting on: `APR-026`,
whose entire scope is a single `Re` value.

```
APR-026 [ECR-D-002]: VOID
C2  FAIL   ECR-D-002 carries an approved disposition
    ! ECR-D-002: approval APR-026 on spec/README.md is VOID -
      the artifact moved without a superseding approval
```

**Meanwhile every other approval naming `ECR-D-002` remained valid** — `APR-019`
SUPERSEDED-VALID, `APR-020` LIVE, `APR-021` LIVE, `APR-023` SUPERSEDED-VALID, `APR-025` LIVE,
`APR-027` LIVE. `C1`, `C3` and `C4` stayed PASS. The criterion can no longer be satisfied by an
arbitrary thin member of the set, and one VOID member is sufficient to fail it. **Repaired as
claimed.**

---

## W6 — the C6 hole `VER-015` disclosed · **FAIL**

**`C6` does read the declared `status`, and it does refuse a non-clearing report.** On the live
repository, `C6` **FAILS** today:

```
! ECR-D-002: VER-015…md declares 'VERIFIED WITH FINDINGS - NOT CLEARED. 7 PASS, 4 FAIL'
  - the report does not clear                              (identically for -003, -004)
```

**And the gate is genuinely gated on the verifier's verdict.** In a temp copy I rewrote
`VER-015`'s status to a clearing value and changed nothing else:

```
C6  PASS   Independent verification recorded per disposition
LC-M04 CAD-READY: YES
```

That is the repair working. It is also the whole gate hanging on one line of one file that the
verifier writes — which is why the status of this report is written to be read literally.

### The defect this trial exposed

**`C6` has no supersession relation between verification reports.** It collects *every* report
whose `subject` names the ECR and requires **all** of them to clear. `VER-015` will declare
`NOT CLEARED` for as long as it exists. Demonstrated directly — a temp copy holding an unmodified
`VER-015` **plus** a `VER-016` declaring a clearing status:

```
+ ECR-D-002: subject of VER-015…md, VER-016…md
! ECR-D-002: VER-015…md declares 'VERIFIED WITH FINDINGS - NOT CLEARED…' - the report does not clear
LC-M04 CAD-READY: NO
```

**No confirmatory round can ever pass `C6` while `VER-015` remains on disk.** Not this one; not
a perfect one.

`DR-004` §4 states: *"`C6` remains FAIL until a verifier files a report that clears, and no edit
to this file can change that."* **That is false as implemented.** `C6` remains FAIL *even when* a
verifier files a report that clears. The approvals layer was given a supersession relation for
precisely this reason — `APR-023` became `SUPERSEDED-VALID` rather than VOID when `APR-027`
superseded it — and the verification layer was given none. The remaining routes out are an
instrument change to `C6` (an ECR and an approval), or rewriting an audit record's verdict to
open a gate, which is inadmissible. **`LC-M04-EXIT` is currently structurally unreachable, and
that is an instrument defect, not an engineering one.**

**Second-order (F-12 below).** The predicate is a keyword match — `\bFAIL\b|NOT CLEARED|NOT
VERIFIED` — over the raw status string. My first trial used the status *"VERIFIED - CLEARED. 11
PASS, 0 FAIL"* and `C6` refused it on the token `FAIL` in *"0 FAIL"*. The direction is fail-safe,
but the `status` field is a keyword slot, not prose, and nothing in the repository says so.

---

## W7 — the V-09 caps · **PASS**

Measured with the repository's own pinned families — TF-1 `cl100k_base`
(pin `223921b7…b2a7`) and TF-2 `spiece.model` (pin `d60acb12…ea86`), both available, special
tokens disabled. **The maximum governs**, per `AIEF-FRZ-001` §1.8.

| File | Cap | TF-1 | TF-2 | Governing | **Margin** | Verdict |
|---|---|---|---|---|---|---|
| `project/STATE.md` | 1100 | 838 | **1035** | 1035 | **65** | WITHIN |
| `project/OPEN_ITEMS.md` | 600 | 457 | **533** | 533 | **67** | WITHIN |

Both breaches are repaired. For context, every other capped T0/T1 file is also within:
`BOOT.md` 504/504 (**margin 0**), `FRAMEWORK.md` 748/1100, `PRECEDENCE.md` 382/700,
`laws/INDEX.md` 721/900, `BINDING.md` 574/800.

Two notes. `DR-004` quotes *"`STATE.md` is reduced to 1097"*; I measure **1035** governing — same
direction, both within cap, but the author's figure is not reproducible under the declared
dual-family maximum rule. And `.ai/core/CONTEXT_TIERS.md` still publishes `BOOT.md` at cap **400**
with a sum of **5800**, against the manifest's **504** and **5904** (F-14 below) — a generated
artifact awaiting the Stage 1 re-emission that `OQ-14` withholds, not a `V-09` breach.

---

## W8 — regression sweep · **FAIL**

`python -m pytest tests/ -q` → **565 passed, 7 failed.**

**(b) Caused by `T-007`/`T-008` and recorded as `OI-C-12` — four tests.** The register row names
exactly these four, and each fails on a count of live, growing project state:

| Test | Observed |
|---|---|
| `test_every_task_record_loads` | extra `T-007`, `T-008` |
| `test_the_live_gap_between_declared_and_effective_is_five_tasks` | 8 producers against 6 |
| `test_the_live_dependency_state_is_derived_end_to_end` | current = `['R-014','R-015']`, expected 1 |
| `test_x09_guards_the_publication_channel_in_both_directions` | reached includes `R-015`, `R-016` |

**(a) Pre-existing on the Stage 6 track — two tests.**

| Test | Observed |
|---|---|
| `test_v24_live_registry` | `framework.manifest.json` DC-1 `920eb6ee…` != registered `8af8971b…` (**ECR-D-006**), and `AIEF-AMD-014` unregistered (**VER-015 F-15**) |
| `test_full_pipeline_with_stub_families` | `PRECONDITION-FAIL ['V-24 FAIL','V-25 FAIL']` — downstream of the same |

**(c) Something else — one test, and this is the one that matters.**

`test_x06_open_on_the_result_that_pins_the_layer_it_describes`, and `X-06` in
`python -m aief_exec check`:

```
X-06  FAIL   Result currency
      FAIL   R-015: declared CURRENT but is STALE
      FAIL     deliverable spec/06_SEWCP-700_Alignment_Pins.md:
                 DC-1 75cda88184e5… != pinned da702fe05f41…
      FAIL     deliverable src/aief_gate/criteria.py:
                 DC-1 ea31104e6447… != pinned 05ec0d519a08…
```

**Both stale pins were moved by the repairs themselves** — the first by the `APR-027` torque
correction (W1), the second by the `C1`–`C4`, `C6` and `C7` instrument changes (W4, W5, W6).
This is **not** a `T-007`/`T-008` count defect and it is **not** covered by `OI-C-12`, whose row
names four tests, all of the counting class.

`DR-004` §3 says *"**Five** exec-layer tests broke on the addition of `T-007`/`T-008`. Recorded
as `OI-C-12`."* It miscounts — four are recorded — and mis-attributes the fifth. **`R-015`, the
result record that publishes the entire LC-M04 coherence package, currently declares
`status: CURRENT` over a state that no longer exists**, and nothing in the repository records
that. It is the stale-label class this project has already been bitten by four times, reappearing
in the record that certifies the repairs.

---

## W9 — has anything new broken? · **PASS**

**1 · All eleven `spec/**` DC-1 digests still match `FROZEN.md`.** Recomputed with my own DC-1:
29 registry rows parsed, no duplicate path, no registered path absent, **11 of 11 `spec/**` rows
reproduce exactly**. Eleven files exist under `spec/` and eleven are registered — none
unregistered. The single registry mismatch repository-wide remains
`framework/framework.manifest.json` (`ECR-D-006`, not under `spec/**`, excluded by name in
`GATES.md`).

**2 · `python -m aief_clearance` still passes.** `CLEARANCE OK`, exit 0. Eight features resolved
from `spec/00` §3.2 and every declared pair clears, including the re-clocked locators at
r = 130 against the outer choke stations.

**3 · `spec/01` and `spec/02` still agree on the choke fastener** — and `spec/00` agrees with
both:

| | `spec/00` §ICD | `spec/01` | `spec/02` |
|---|---|---|---|
| Fastener | **M5 × 25** SHCS, 12 + 4, 3.5 N·m | `CP-IF-3` **M5 × 25**, *"not M5 × 30"* | §10 step 13 **M5 × 25**, *"Do not substitute M5 × 30"* |
| `CP-D26` | slotted counterbore, Cooling Plate | **11.0 W × 12.5 L × 2.5 deep**, +0.20/−0, masked | referenced, consistent |
| `HP-D12` | helical inserts, Heater Plate | referenced | **6.50 +0.30/−0 deep**, 1.50 mm min to bond face, engages 5.40 mm |

No divergence. Nothing in criteria 1–3 was damaged by the repairs.

---

## W10 — the honest question · **FAIL**

> **Is there anything in this repository that should stop someone opening Fusion 360 and
> modelling SEWCP-200 tomorrow?**

## **Yes.**

**The specification set is not the problem.** I found no contradiction in `spec/**`; W1, W3 and
W9 all hold. The problem is the artifact `STATE.md.next_action` sends the modeller to:
`implementation/01_SEWCP-200_Cooling_Plate/SEWCP-200_CAD_Implementation_Package.md`.

**1 · The parameter master still carries the exact collision `ECR-D-010` exists to prevent.**
§3.3 line 213:

```
| `ang_kin_top_1/2/3` | Top locator angles | `30.0` / `150.0` / `270.0` | deg | Vol 00 §3.2 | — |
```

`spec/00` §3.2 line 119 now reads **75°, 195°, 315°**, and line 125 records what 30°/150°/270°
did: *"sat on three outer choke rays, overlapping the M5 slot by 4.5 mm radially and the Ø22
washer pad almost completely."* The package's **own banner**, line 52, states the re-clocking —
and then its parameter table, its timeline step 11 (line 312) and its modelling step 6.34 (line
395) all still carry 30/150/270. Step 6.34 is labelled *"**discharged**"* while carrying the
colliding number. **A modeller who follows §6 in order builds the collision.** This is the single
most dangerous thing in the repository right now, because it is not a stale note in a history
section — it is the live parameter master, and it cites as its authority a document that now says
the opposite.

**2 · Two dimensions the modeller needs are still the literal string `UNSPECIFIED`.** §3.4 lines
238–239, `choke_cbore_d` and `choke_cbore_dep`, both still tagged **HOLD H3** — when `ECR-D-004`
fixed them at 11.0 W × 12.5 L × 2.5 deep and the banner declares H3 discharged. Timeline step 13
asks for those counterbores. Step 6.02's acceptance criterion is *"Parameter count matches §3"* —
which it does, with two of the values being the word UNSPECIFIED.

**3 · The sketch table still offers the superseded Ø12 geometry as a live alternative.** Line
351, sketch S11, marked **RESOLVED**: *"Ø6.000 H7 bore (Vol 01) **or** Ø12.0 H7 × 3.0 counterbore
+ M4 tap (Vol 06)"*. `ECR-D-001` ruled SEWCP-700 governs — it is not an "or" — and `ECR-D-007`
action 3 took Ø12.0 → **Ø10.0**. This is the same superseded Ø12 arithmetic `VER-015` F-05 found
in `ECR-D-007` §8/§9: repaired there, not repaired here.

**4 · The import the procedure depends on does not exist.** Step 6.02 imports
`params/generated/SEWCP-200.csv`. `params/generated/` contains only `.gitkeep`. The modeller
necessarily falls back to typing §3 by hand — the tables in (1) and (2).

**The disclaimer does not discharge this.** The package does say *"Where this package and
`spec/**` disagree, `spec/**` governs"*, and that is honest. But a parameter master exists so
that the modeller does **not** re-derive values from the specification, and §6.02 instructs them
to import it. A disclaimer that requires re-checking every value against the spec makes the
package worthless as a package, and no modeller reads it that way.

**`OI-P-03` claims the package was *"Corrected in this session so the package is usable for
CAD"*, and the banner claims *"the numeric errors that would have misled a modeller are corrected
in place below."* Both claims are false for items 1–3. That is a cosmetic repair presented as a
real one, and it is the finding.**

**Do not open Fusion 360 against this package** until §3.3 `ang_kin_top_*`, §3.4 `choke_cbore_*`,
sketch S11 and step 6.34 are corrected. Modelling directly from `spec/00`, `spec/01` and
`spec/06` is safe today — those three are coherent and hash-registered.

---

## Findings

| ID | Finding | Severity | Owner | Criterion |
|---|---|---|---|---|
| **F-01** | **`C6` has no supersession relation between verification reports.** It requires *every* report naming the ECR to clear, so `VER-015`'s `NOT CLEARED` blocks the gate permanently. Demonstrated: a clearing `VER-016` alongside an unmodified `VER-015` still fails `C6`. **`LC-M04-EXIT` is structurally unreachable.** `DR-004` §4's *"C6 remains FAIL until a verifier files a report that clears"* is false as implemented | **HIGH** | chief-systems-engineer + A4 | W6 |
| **F-02** | **The CAD package's parameter master still carries `ang_kin_top_1/2/3` = 30/150/270**, the clocking `ECR-D-010` was raised to remove, sourced to a `spec/00` §3.2 that now says 75/195/315. Timeline step 11 and modelling step 6.34 carry it too, the latter labelled "discharged". A modeller following §6 builds the collision | **HIGH** | mechanical.cad-engineer | W10 |
| **F-03** | `choke_cbore_d` / `choke_cbore_dep` still read **UNSPECIFIED** and are tagged HOLD H3, though `ECR-D-004` dispositioned them at 11.0 W × 12.5 L × 2.5 deep and the banner declares H3 discharged | **MEDIUM** | mechanical.cad-engineer | W10 |
| **F-04** | Sketch S11 still offers **Ø12.0 H7 × 3.0** as a live alternative marked RESOLVED. Superseded twice over: `ECR-D-001` (SEWCP-700 governs, not an "or") and `ECR-D-007` action 3 (Ø12.0 → Ø10.0) | **MEDIUM** | mechanical.cad-engineer | W10 |
| **F-05** | **`R-015` declares `status: CURRENT` but is STALE** — it pins `spec/06` at `da702fe0…` and `criteria.py` at `05ec0d51…`, both moved by the repairs. Not recorded anywhere; **not** covered by `OI-C-12`, which names four tests of a different class. `DR-004` §3 miscounts five and mis-attributes this one | **MEDIUM** | software.software-engineer | W8 |
| **F-06** | `params/generated/SEWCP-200.csv` does not exist; the directory holds only `.gitkeep`. Step 6.02 is unexecutable as written | **LOW** | mechanical.cad-engineer | W10 |
| **F-07** | `ECR-Q-003`'s `approval:` reads `project/approvals/APR-004_…`, a grammar no other record uses; it resolves to `.ai/project/project/approvals/…`, which does not exist. Surviving F-22 instance | **LOW** | chief-systems-engineer | W2 |
| **F-08** | `APR-001` … `APR-013` carry no `ecr:` field, so `ECR-D-005`, `ECR-Q-001`, `ECR-Q-002` and `ECR-Q-003` have no back-reference. `DR-004`'s *"every named approval lists the ECR"* holds only for the nine `spec/**` records | **LOW** | chief-systems-engineer | W2 |
| **F-09** | `FROZEN.md` § *Registration history* has **no row** for the `APR-027` re-registration of `spec/06`. Every other registry change has one; this event survives only as prose in § *Aggregate* | **LOW** | chief-systems-engineer | W1 |
| **F-10** | `ECR-D-009` still points `approval:` at the superseded `APR-023`, never names `APR-027`, and still asserts *"both are corrected"* enumerating only `spec/01`'s two sites — the sentence that concealed F-08, with the third site still unnamed | **LOW** | chief-systems-engineer | W1 |
| **F-11** | `C7`'s evidence lines are unconditional prose emitted even when the residue contradicts them — printing *"all carry a non-empty disposition"* and *"is consistent with them"* in the same output that disproves both | **LOW** | software.software-engineer | W4 |
| **F-12** | `C6`'s status predicate is a keyword match over the raw string; a genuinely clearing status reading *"… 0 FAIL"* is refused on the token. Fail-safe, but the field is an undocumented keyword slot | **LOW** | software.software-engineer | W6 |
| **F-13** | `FROZEN.md` § *Standing verification* still reads *"**None yet** … `V-24` … is **not implemented as software**"*. `V-24` **is** implemented (`aief_stage6.preconditions.check_v24`) and runs in the suite — where it currently fails on `ECR-D-006` | **LOW** | chief-systems-engineer | W1 · W8 |
| **F-14** | `.ai/core/CONTEXT_TIERS.md` publishes `BOOT.md` cap **400** and sum **5800** against the manifest's **504** and **5904**. Generated artifact awaiting the Stage 1 re-emission `OQ-14` withholds; recorded, not a `V-09` breach | **INFO** | repository-engineer | W7 |

---

## Verdict

| Criterion | Subject | Verdict |
|---|---|---|
| **W1** | F-08 — the torque, and its binding | **PASS** |
| **W2** | F-22 — the ECR references | **FAIL** |
| **W3** | F-05 / F-06 — `ECR-D-007` §8/§9 and `ECR-D-012` | **PASS** |
| **W4** | F-18 — the `C7` evasion, both directions | **PASS** |
| **W5** | F-19 — the thin-approval hole | **PASS** |
| **W6** | the `C6` hole `VER-015` disclosed | **FAIL** |
| **W7** | the `V-09` caps | **PASS** |
| **W8** | regression sweep | **FAIL** |
| **W9** | has anything new broken | **PASS** |
| **W10** | the honest question | **FAIL** |

### **6 PASS · 4 FAIL**

**The engineering repairs are real.** F-08, F-05, F-06, F-18, F-19 and the `V-09` breaches were
all repaired at the artifact, not at the description of it, and each was confirmed here by
independent recomputation or by re-running the original attack. The two instrument repairs —
`C7` reading the records rather than the index, and `C1`–`C4` requiring every naming approval to
be non-VOID — are the most valuable work in the session and both survive adversarial trial.
`DR-004` contested nothing and that was correct.

**Three things stop this gate.**

1. **`C6` cannot be satisfied by any report.** Absent a supersession relation between
   verification reports, `VER-015`'s recorded verdict blocks `LC-M04-EXIT` permanently. This
   round cannot clear it and neither can a perfect one. **F-01 must be dispositioned before any
   verifier is dispatched again**, or the next round burns for nothing.
2. **The CAD package would mislead a modeller into the `ECR-D-010` collision.** F-02 is a
   correctness defect in the one artifact the project's own `next_action` directs a modeller to
   open. The specification is right; the thing built from it is not.
3. **A repair broke a record and the disposition did not notice.** F-05 — `R-015` is stale, and
   `DR-004`'s account of the test failures is wrong about both the count and the cause.

**`LC-M04-EXIT` is NOT passed. CAD is NOT authorised on the strength of this round.** Confirmed
by execution, not asserted: `python -m aief_gate` reports **`LC-M04 CAD-READY: NO`** with `C6`
FAIL at the recorded instant.

**Nothing in `spec/**` blocks modelling.** Whoever repairs F-02 first should note that the
correct value is already frozen, registered and computed — `spec/00` §3.2 line 119, and
`python -m aief_clearance`.

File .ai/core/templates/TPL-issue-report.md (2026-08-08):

# TPL - Issue Report

> **Generated artifact.** Emitted by aief-compile Stage 2 from `framework.manifest.json`.
> Do not edit. Regenerate from the manifest.

| | |
|---|---|
| Framework | AIEF 1.0.0 |
| File id | `tpl-issue-report` |
| Layer / partition | L2 / core |
| Tier | T3 |
| Owner | `project-manager` |
| Mutability | immutable |
| Producer | any agent |
| Consumers | `project-manager` |
| Filed at | `project/issues/` |
| Authority | workflow `WF-02` |

---

For observations that are **not** challenges to an authority. Where a finding contradicts a frozen artifact, a law or a specification, the instrument is an **ECR**, not an issue report.

| Use an issue report for | Use an ECR for |
|---|---|
| Tooling, process and infrastructure friction | Ambiguity in an authority - **ECR-Q** |
| Housekeeping and hygiene | Defect in an authority - **ECR-D** |
| Anything with no authority conflict | Anything requiring a ruling |

## Required sections

### 1 · Description

What was observed, factually. Separate observation from interpretation; the two are not equally reliable and a reader must be able to tell them apart.

### 2 · Severity

| Severity | Meaning | Response |
|---|---|---|
| **Critical** | Work cannot proceed | Immediate `project-manager` attention |
| **Major** | Work proceeds with material friction or risk | Scheduled |
| **Minor** | Inconvenience; no risk to deliverables | Backlog |
| **Observation** | Recorded for pattern detection | None required |

Severity is always assigned. An unassigned severity cannot be triaged and will be ignored.

### 3 · Reproduction

The steps that produce the observation, with environment and inputs. Where the issue is not reproducible, **declare that explicitly** - an intermittent issue that says so is actionable, one that stays silent is not.

### 4 · Affected artifacts

| Path | Effect |
|---|---|

Where nothing in the repository is affected, state the affected process or tooling instead.

### 5 · Proposed disposition

What the raiser suggests. Advisory only: disposition belongs to `project-manager`. Where the proposal turns out to require a ruling against an authority, the issue is **converted to an ECR** and this file records the conversion.

## Acceptance conditions

| # | Condition | Test |
|---|---|---|
| 1 | Severity assigned | §2 states one of the four levels |
| 2 | Reproduction stated or declared unavailable | §3 gives steps or explicitly declares non-reproducibility |

## Forbidden

| | |
|---|---|
| Using an issue report to challenge a frozen artifact | That requires an ECR - `LAW-02` |
| Filing without a severity | Condition 1 |
| Treating a proposed disposition as a decision | Disposition is `project-manager` authority |

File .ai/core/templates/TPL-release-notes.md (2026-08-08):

# TPL - Release Notes

> **Generated artifact.** Emitted by aief-compile Stage 2 from `framework.manifest.json`.
> Do not edit. Regenerate from the manifest.

| | |
|---|---|
| Framework | AIEF 1.0.0 |
| File id | `tpl-release-notes` |
| Layer / partition | L2 / core |
| Tier | T3 |
| Owner | `repository-engineer` |
| Mutability | immutable |
| Producer | `repository-engineer` |
| Consumers | `human-owner` |
| Filed at | `project/releases/` |
| Authority | `LAW-07` Git and Configuration Control · workflow `WF-05` |

---

`repository-engineer` owns all repository operations and executes the release sequence **automatically once a release gate is approved**. No release occurs without an approved gate disposition.

## Required sections

### 1 · Version

| | |
|---|---|
| Version | semantic |
| Previous version | |
| Date | ISO-8601 UTC |
| Gate disposition | the approved gate authorising this release |

### 2 · Tag

| | |
|---|---|
| Tag | annotated - never lightweight |
| Target commit | full SHA |
| Author = committer = repository owner | **confirmed** |
| Remote | pushed and verified |

Tags are annotated and **never moved**. Published history is never rewritten.

### 3 · Contents

What changed, at the level a human owner needs to make a decision. Group by area; cite artifacts by path. Note anything that changes an interface, a frozen artifact or the framework binding.

### 4 · Integrity statement

**Must state the verification method**, not merely assert that verification occurred.

| Check | Method | Result |
|---|---|---|
| Working tree clean | `git status --porcelain` empty | |
| Remote branch synchronised | | |
| Remote tags present | | |
| Commit SHA verified | | |
| Release tag target verified | | |
| Author = committer = owner | | |
| Frozen set verifies | normalised SHA-256 per `FROZEN.md` | |

Post-release verification is mandatory. **A repository policy violation is a QA failure, never a warning** - enforced by `V-22`.

### 5 · Known open items

Every open item at the moment of release, or **explicitly none**. Silence is not an acceptable value: a reader cannot distinguish *no open items* from *not checked*.

| ID | Item | Blocks |
|---|---|---|

## Acceptance conditions

| # | Condition | Test |
|---|---|---|
| 1 | Integrity statement states verification method | §4 names the method per check, not just a result |
| 2 | Open items listed or explicitly none | §5 is non-empty or states *none* explicitly |

## Forbidden

| | |
|---|---|
| Modifying git author or committer identity | `LAW-07` |
| Adding attribution, co-author or generated-by trailers | `LAW-07` |
| Moving a tag · rewriting published history | `LAW-07` |
| Force push unless explicitly authorised | `LAW-07` - escalate to human |
| Releasing without an approved gate disposition | `LAW-03` |
| Generating `MANIFEST.lock` outside Compiler Stage 6 | Stage 6 barrier |

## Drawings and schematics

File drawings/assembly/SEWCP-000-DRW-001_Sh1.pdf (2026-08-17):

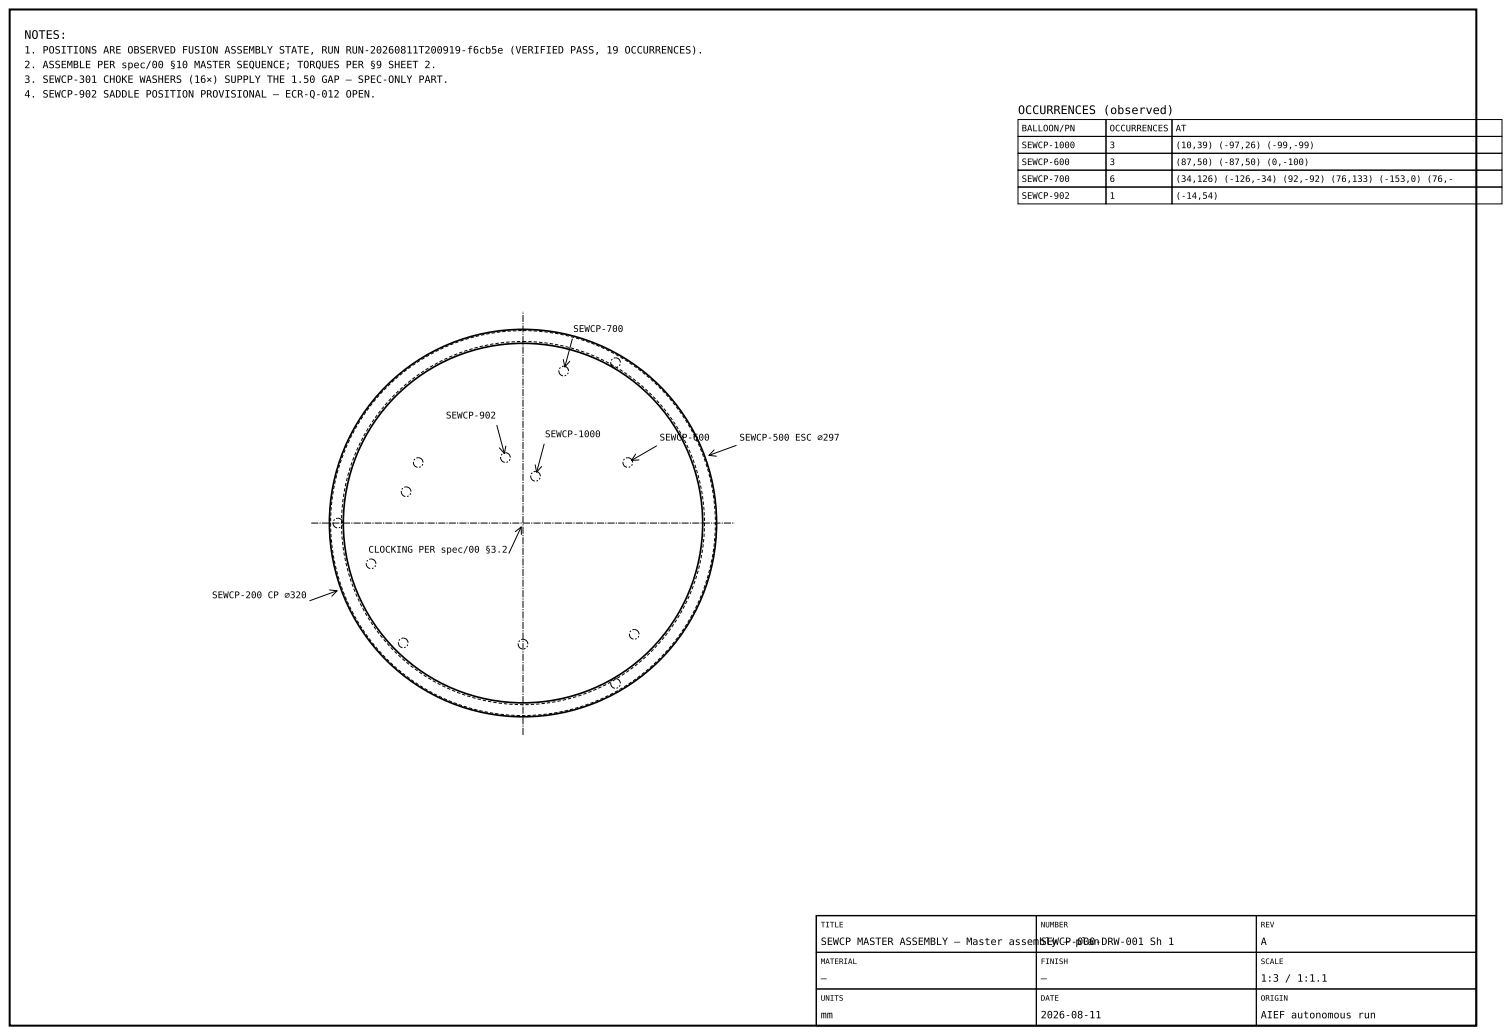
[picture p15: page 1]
SEWCP-600; SEWCP-700; SEWCP-902; SEWCP-1000; SEWCP-200 CP ⌀320; SEWCP-500 ESC ⌀297; OCCURRENCES (observed)

NOTES:
1. POSITIONS ARE OBSERVED FUSION ASSEMBLY STATE, RUN RUN-20260811T200919-f6cb5e (VERIFIED PASS, 19 OCCURRENCES).
2. ASSEMBLE PER spec/00 §10 MASTER SEQUENCE; TORQUES PER §9 SHEET 2.
3. SEWCP-301 CHOKE WASHERS (16×) SUPPLY THE 1.50 GAP — SPEC-ONLY PART.
4. SEWCP-902 SADDLE POSITION PROVISIONAL — ECR-Q-012 OPEN.

BALLOON/PN | OCCURRENCES | AT
SEWCP-1000 | 3 | (10,39) (-97,26) (-99,-99)
SEWCP-600 | 3 | (87,50) (-87,50) (0,-100)
SEWCP-700 | 6 | (34,126) (-126,-34) (92,-92) (76,133) (-153,0) (76,-
SEWCP-902 | 1 | (-14,54)

CLOCKING PER spec/00 §3.2

TITLE SEWCP MASTER ASSEMBLY — Master assembly — plan | NUMBER SEWCP-000-DRW-001 Sh 1 | REV A

MATERIAL — | FINISH — | SCALE 1:3 / 1:1.1

UNITS mm | DATE 2026-08-11 | ORIGIN AIEF autonomous run

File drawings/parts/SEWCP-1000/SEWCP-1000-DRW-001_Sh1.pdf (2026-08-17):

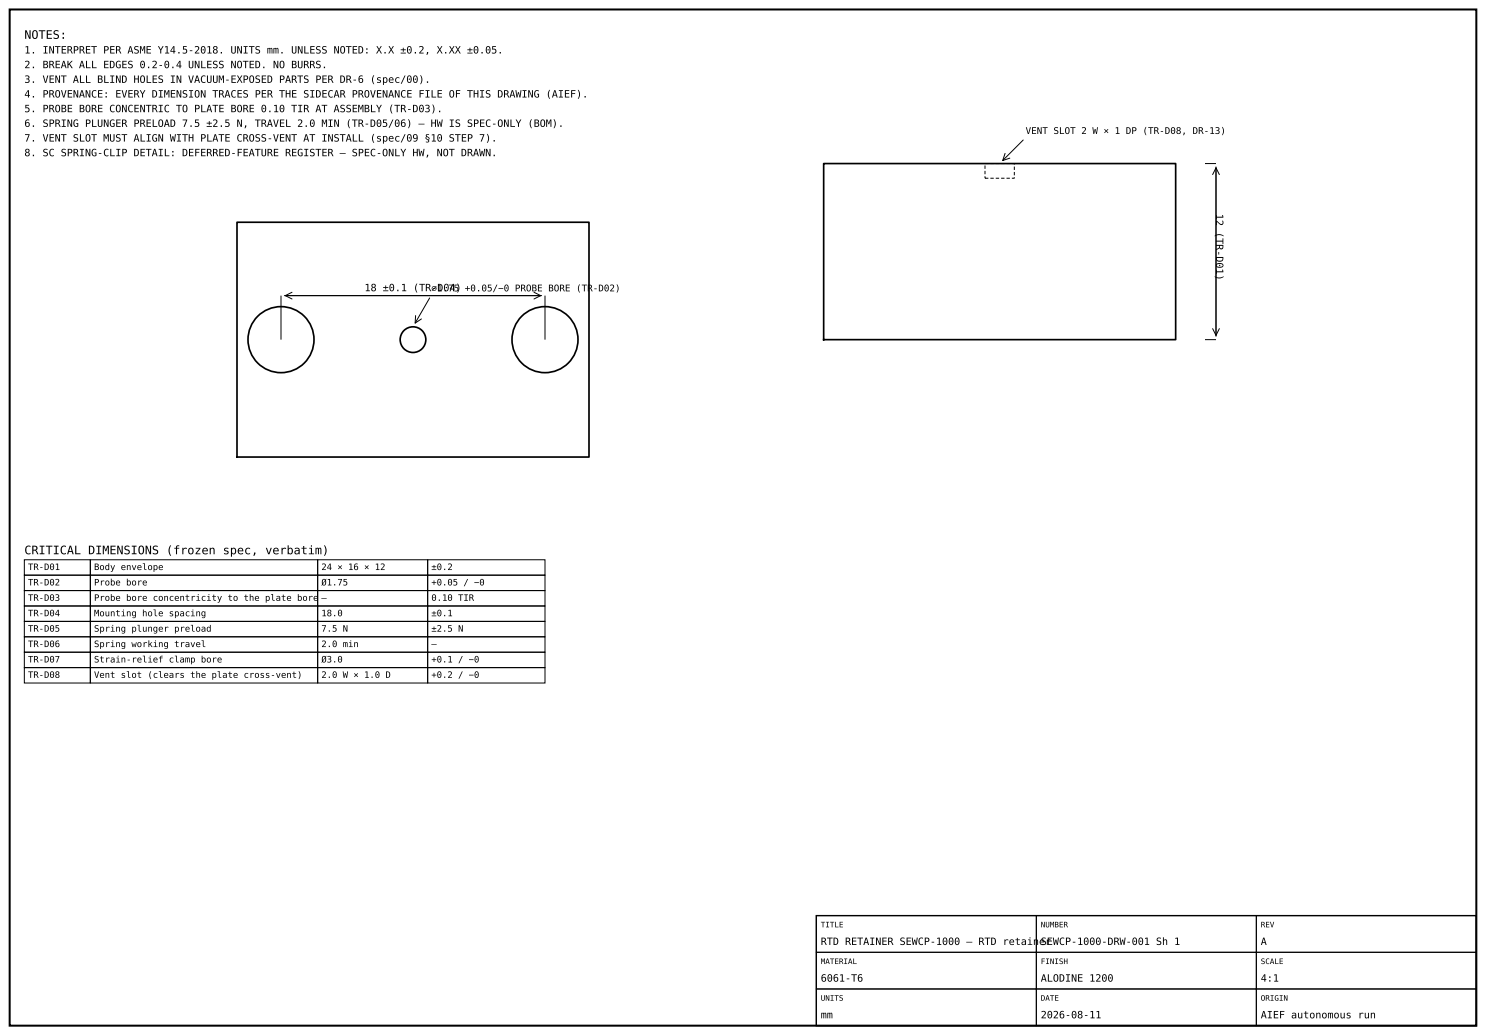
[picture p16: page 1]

NOTES:
1. INTERPRET PER ASME Y14.5-2018. UNITS mm. UNLESS NOTED: X.X ±0.2, X.XX ±0.05.
2. BREAK ALL EDGES 0.2-0.4 UNLESS NOTED. NO BURRS.
3. VENT ALL BLIND HOLES IN VACUUM-EXPOSED PARTS PER DR-6 (spec/00).
4. PROVENANCE: EVERY DIMENSION TRACES PER THE SIDECAR PROVENANCE FILE OF THIS DRAWING (AIEF).
5. PROBE BORE CONCENTRIC TO PLATE BORE 0.10 TIR AT ASSEMBLY (TR-D03).
6. SPRING PLUNGER PRELOAD 7.5 ±2.5 N, TRAVEL 2.0 MIN (TR-D05/06) — HW IS SPEC-ONLY (BOM).
7. VENT SLOT MUST ALIGN WITH PLATE CROSS-VENT AT INSTALL (spec/09 §10 STEP 7).
8. SC SPRING-CLIP DETAIL: DEFERRED-FEATURE REGISTER — SPEC-ONLY HW, NOT DRAWN.

VENT SLOT 2 W × 1 DP (TR-D08, DR-13)

18 ±0.1 (TR-D04) ⌀1.75 +0.05/−0 PROBE BORE (TR-D02)

CRITICAL DIMENSIONS (frozen spec, verbatim)

TR-D01 | Body envelope | 24 × 16 × 12 | ±0.2
TR-D02 | Probe bore | Ø1.75 | +0.05 / −0
TR-D03 | Probe bore concentricity to the plate bore | — | 0.10 TIR

TR-D04 | Mounting hole spacing | 18.0 | ±0.1
TR-D05 | Spring plunger preload | 7.5 N | ±2.5 N
TR-D06 | Spring working travel | 2.0 min | —
TR-D07 | Strain-relief clamp bore | Ø3.0 | +0.1 / −0
TR-D08 | Vent slot (clears the plate cross-vent) | 2.0 W × 1.0 D | +0.2 / −0

TITLE RTD RETAINER SEWCP-1000 — RTD retainer | NUMBER SEWCP-1000-DRW-001 Sh 1 | REV A

MATERIAL 6061-T6 | FINISH ALODINE 1200 | SCALE 4:1

UNITS mm | DATE 2026-08-11 | ORIGIN AIEF autonomous run

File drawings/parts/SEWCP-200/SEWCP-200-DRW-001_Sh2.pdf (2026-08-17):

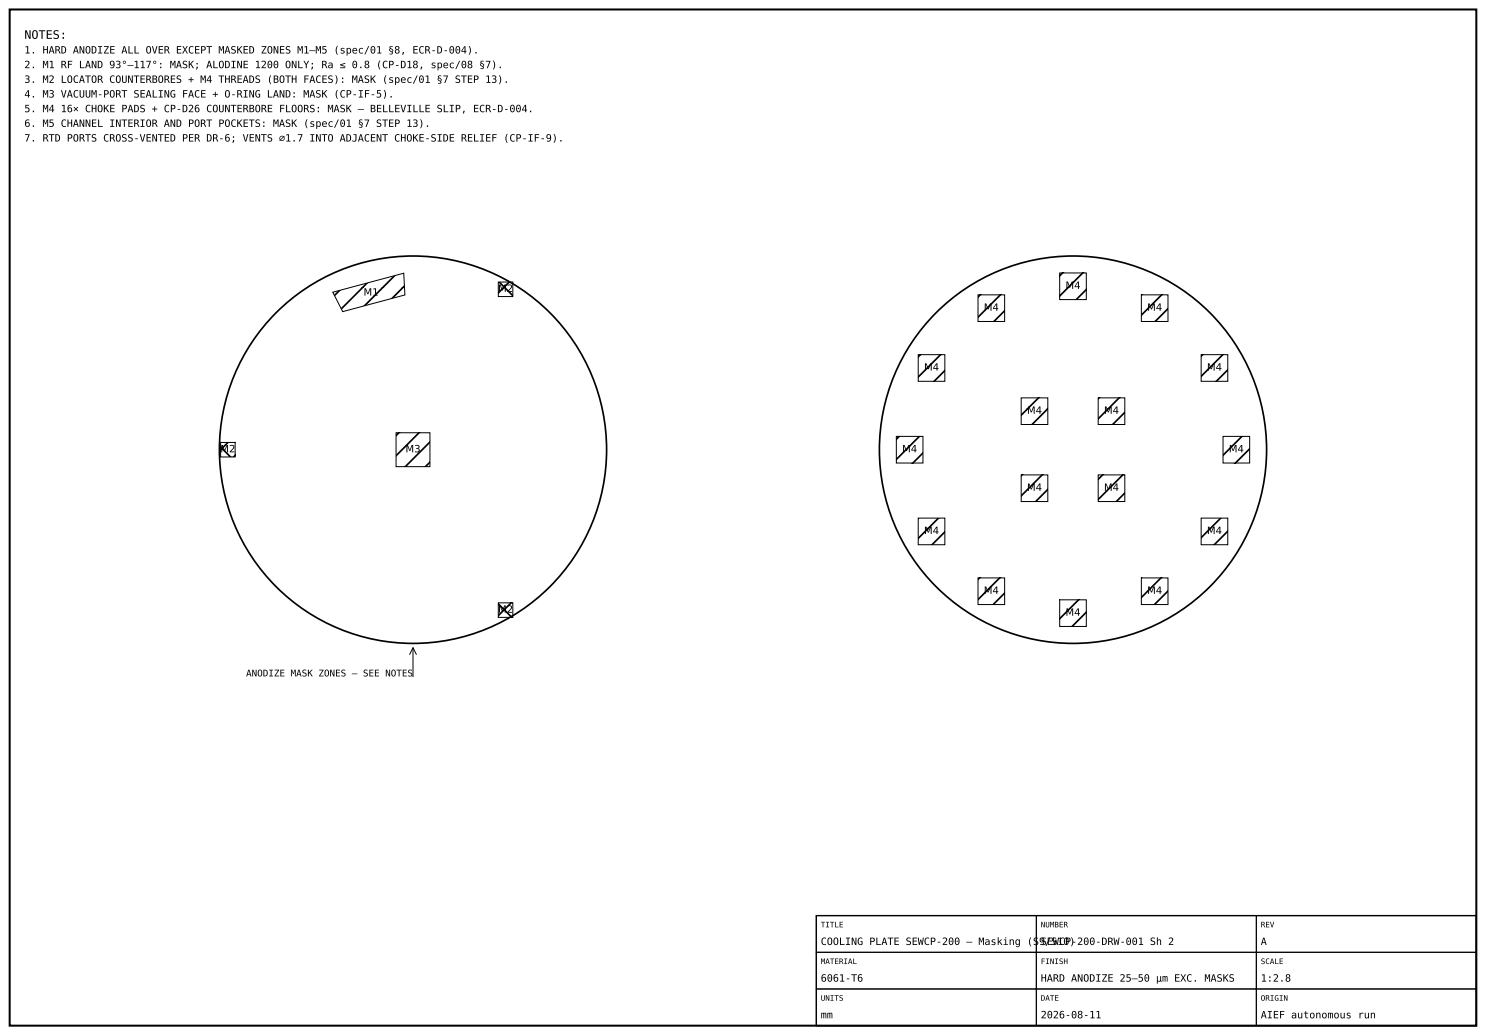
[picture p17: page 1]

NOTES:
1. HARD ANODIZE ALL OVER EXCEPT MASKED ZONES M1–M5 (spec/01 §8, ECR-D-004).
2. M1 RF LAND 93°–117°: MASK; ALODINE 1200 ONLY; Ra ≤ 0.8 (CP-D18, spec/08 §7).
3. M2 LOCATOR COUNTERBORES + M4 THREADS (BOTH FACES): MASK (spec/01 §7 STEP 13).
4. M3 VACUUM-PORT SEALING FACE + O-RING LAND: MASK (CP-IF-5).
5. M4 16× CHOKE PADS + CP-D26 COUNTERBORE FLOORS: MASK — BELLEVILLE SLIP, ECR-D-004.
6. M5 CHANNEL INTERIOR AND PORT POCKETS: MASK (spec/01 §7 STEP 13).
7. RTD PORTS CROSS-VENTED PER DR-6; VENTS ⌀1.7 INTO ADJACENT CHOKE-SIDE RELIEF (CP-IF-9).

ANODIZE MASK ZONES — SEE NOTES

TITLE COOLING PLATE SEWCP-200 — Masking (S9/S10) | NUMBER SEWCP-200-DRW-001 Sh 2 | REV A

MATERIAL 6061-T6 | FINISH HARD ANODIZE 25–50 µm EXC. MASKS | SCALE 1:2.8

UNITS mm | DATE 2026-08-11 | ORIGIN AIEF autonomous run

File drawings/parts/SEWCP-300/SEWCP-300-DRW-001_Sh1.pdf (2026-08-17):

## NOTES:

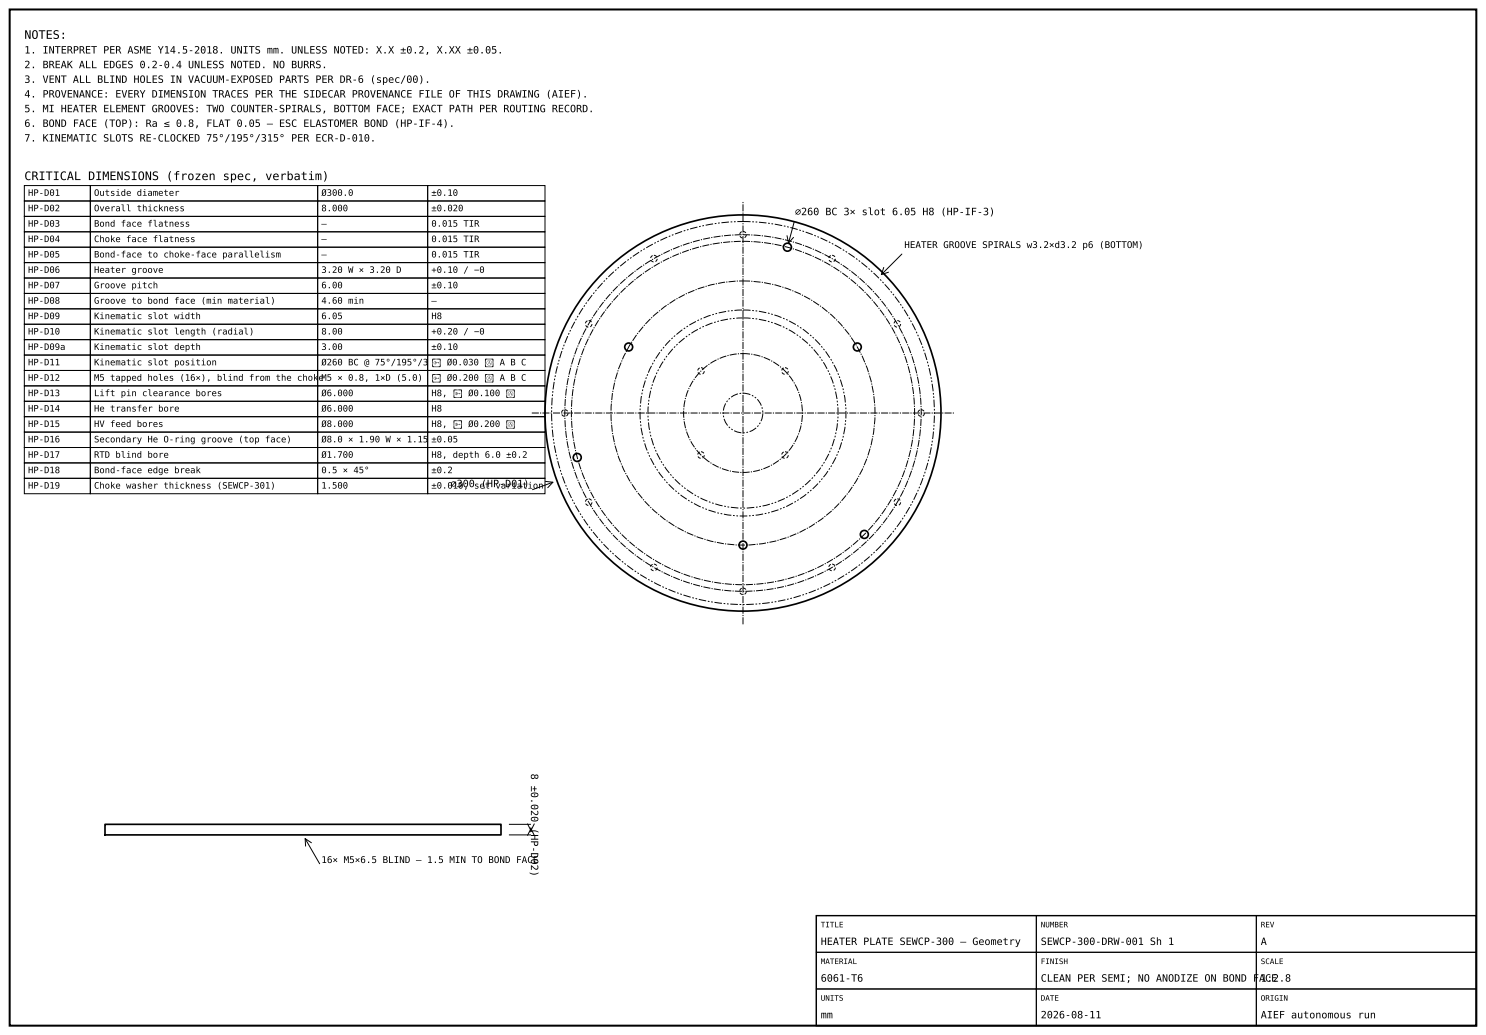
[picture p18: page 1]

1. INTERPRET PER ASME Y14.5-2018. UNITS mm. UNLESS NOTED: X.X ±0.2, X.XX ±0.05.
2. BREAK ALL EDGES 0.2-0.4 UNLESS NOTED. NO BURRS.
3. VENT ALL BLIND HOLES IN VACUUM-EXPOSED PARTS PER DR-6 (spec/00).
4. PROVENANCE: EVERY DIMENSION TRACES PER THE SIDECAR PROVENANCE FILE OF THIS DRAWING (AIEF).
5. MI HEATER ELEMENT GROOVES: TWO COUNTER-SPIRALS, BOTTOM FACE; EXACT PATH PER ROUTING RECORD.
6. BOND FACE (TOP): Ra ≤ 0.8, FLAT 0.05 — ESC ELASTOMER BOND (HP-IF-4).
7. KINEMATIC SLOTS RE-CLOCKED 75°/195°/315° PER ECR-D-010.

CRITICAL DIMENSIONS (frozen spec, verbatim)

HP-D01 | Outside diameter | Ø300.0 | ±0.10
HP-D02 | Overall thickness | 8.000 | ±0.020
HP-D03 | Bond face flatness | — | 0.015 TIR
HP-D04 | Choke face flatness | — | 0.015 TIR
HP-D05 | Bond-face to choke-face parallelism | — | 0.015 TIR
HP-D06 | Heater groove | 3.20 W × 3.20 D | +0.10 / −0

⌀260 BC 3× slot 6.05 H8 (HP-IF-3)

HEATER GROOVE SPIRALS w3.2×d3.2 p6 (BOTTOM)

HP-D07 | Groove pitch | 6.00 | ±0.10
HP-D08 | Groove to bond face (min material) | 4.60 min | —

HP-D09 | Kinematic slot width | 6.05 | H8
HP-D10 | Kinematic slot length (radial) | 8.00 | +0.20 / −0

HP-D09a | Kinematic slot depth | 3.00 | ±0.10
HP-D11 | Kinematic slot position | Ø260 BC @ 75°/195°/3 | ⌖ Ø0.030 Ⓜ A B C
HP-D12 | M5 tapped holes (16×), blind from the choke M5 × 0.8, 1×D (5.0) | | ⌖ Ø0.200 Ⓜ A B C
HP-D13 | Lift pin clearance bores | Ø6.000 | H8, ⌖ Ø0.100 Ⓜ

HP-D14 | He transfer bore | Ø6.000 | H8
HP-D15 | HV feed bores | Ø8.000 | H8, ⌖ Ø0.200 Ⓜ

HP-D16 | Secondary He O-ring groove (top face) | Ø8.0 × 1.90 W × 1.15 | ±0.05
HP-D17 | RTD blind bore | Ø1.700 | H8, depth 6.0 ±0.2
HP-D18 | Bond-face edge break | 0.5 × 45° | ±0.2
HP-D19 | Choke washer thickness (SEWCP-301) | 1.500 | ⌀300 (HP-D01) ±0.010, set variation

16× M5×6.5 BLIND — 1.5 MIN TO BOND FACE

TITLE HEATER PLATE SEWCP-300 — Geometry | NUMBER SEWCP-300-DRW-001 Sh 1 | REV A

MATERIAL 6061-T6 | FINISH CLEAN PER SEMI; NO ANODIZE ON BOND FACE | SCALE 1:2.8

UNITS mm | DATE 2026-08-11 | ORIGIN AIEF autonomous run

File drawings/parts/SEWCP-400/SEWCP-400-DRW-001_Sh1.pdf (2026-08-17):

## NOTES:

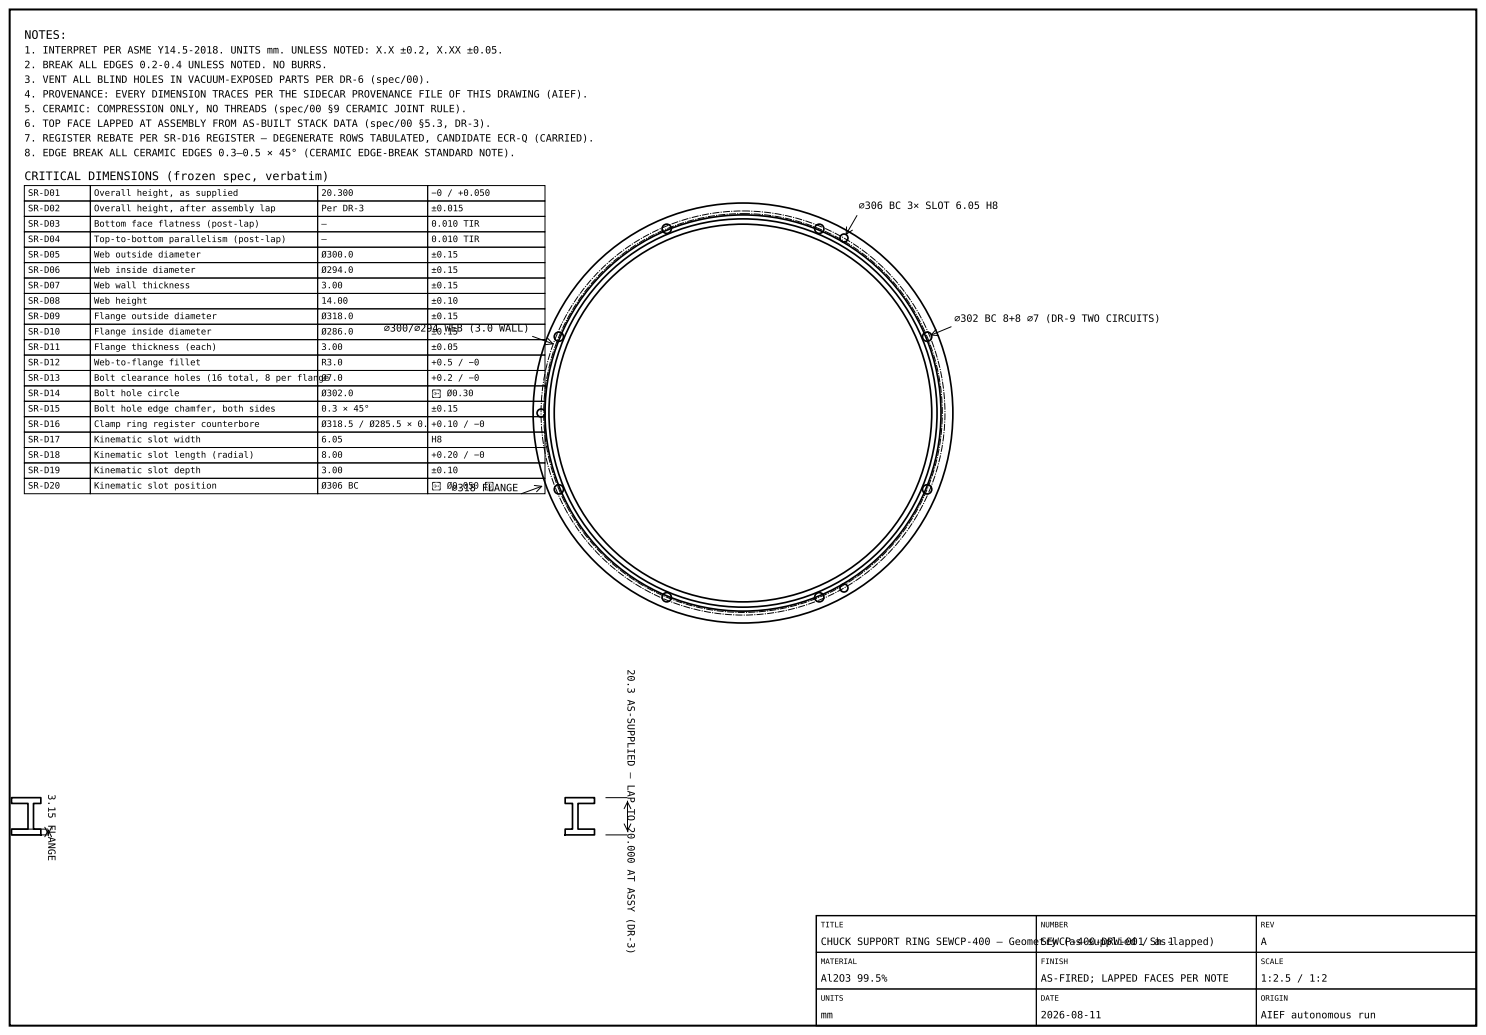
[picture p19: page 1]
⌀306 BC 3× SLOT 6.05 H8; 3.15 FLANGE

1. INTERPRET PER ASME Y14.5-2018. UNITS mm. UNLESS NOTED: X.X ±0.2, X.XX ±0.05.
2. BREAK ALL EDGES 0.2-0.4 UNLESS NOTED. NO BURRS.
3. VENT ALL BLIND HOLES IN VACUUM-EXPOSED PARTS PER DR-6 (spec/00).
4. PROVENANCE: EVERY DIMENSION TRACES PER THE SIDECAR PROVENANCE FILE OF THIS DRAWING (AIEF).
5. CERAMIC: COMPRESSION ONLY, NO THREADS (spec/00 §9 CERAMIC JOINT RULE).
6. TOP FACE LAPPED AT ASSEMBLY FROM AS-BUILT STACK DATA (spec/00 §5.3, DR-3).
7. REGISTER REBATE PER SR-D16 REGISTER — DEGENERATE ROWS TABULATED, CANDIDATE ECR-Q (CARRIED).
8. EDGE BREAK ALL CERAMIC EDGES 0.3–0.5 × 45° (CERAMIC EDGE-BREAK STANDARD NOTE).

CRITICAL DIMENSIONS (frozen spec, verbatim)

SR-D01 | Overall height, as supplied | 20.300 | −0 / +0.050

SR-D02 | Overall height, after assembly lap | Per DR-3 | ±0.015
SR-D03 | Bottom face flatness (post-lap) | — | 0.010 TIR
SR-D04 | Top-to-bottom parallelism (post-lap) | — | 0.010 TIR

SR-D05 | Web outside diameter | Ø300.0 | ±0.15
SR-D06 | Web inside diameter | Ø294.0 | ±0.15
SR-D07 | Web wall thickness | 3.00 | ±0.15
SR-D08 | Web height | 14.00 | ±0.10
SR-D09 | Flange outside diameter | Ø318.0 | ±0.15
SR-D10 | Flange inside diameter | ⌀300/⌀294 WEB (3.0 WALL) Ø286.0 | ±0.15

⌀302 BC 8+8 ⌀7 (DR-9 TWO CIRCUITS)

SR-D11 | Flange thickness (each) | 3.00 | ±0.05
SR-D12 | Web-to-flange fillet | R3.0 | +0.5 / −0
SR-D13 | Bolt clearance holes (16 total, 8 per flangeØ7.0 | | +0.2 / −0

SR-D14 | Bolt hole circle | Ø302.0 | ⌖ Ø0.30

SR-D15 | Bolt hole edge chamfer, both sides | 0.3 × 45° | ±0.15
SR-D16 | Clamp ring register counterbore | Ø318.5 / Ø285.5 × 0. | +0.10 / −0

SR-D17 | Kinematic slot width | 6.05 | H8
SR-D18 | Kinematic slot length (radial) | 8.00 | +0.20 / −0

SR-D19 | Kinematic slot depth | 3.00 | ±0.10
SR-D20 | Kinematic slot position | Ø306 BC | ⌀318 FLANGE ⌖ Ø0.050 Ⓜ

20.3 AS-SUPPLIED — LAP TO 20.000 AT ASSY (DR-3)

TITLE CHUCK SUPPORT RING SEWCP-400 — Geometry (as-supplied / as-lapped) | NUMBER SEWCP-400-DRW-001 Sh 1 | REV A

MATERIAL Al2O3 99.5% | FINISH AS-FIRED; LAPPED FACES PER NOTE | SCALE 1:2.5 / 1:2

UNITS mm | DATE 2026-08-11 | ORIGIN AIEF autonomous run

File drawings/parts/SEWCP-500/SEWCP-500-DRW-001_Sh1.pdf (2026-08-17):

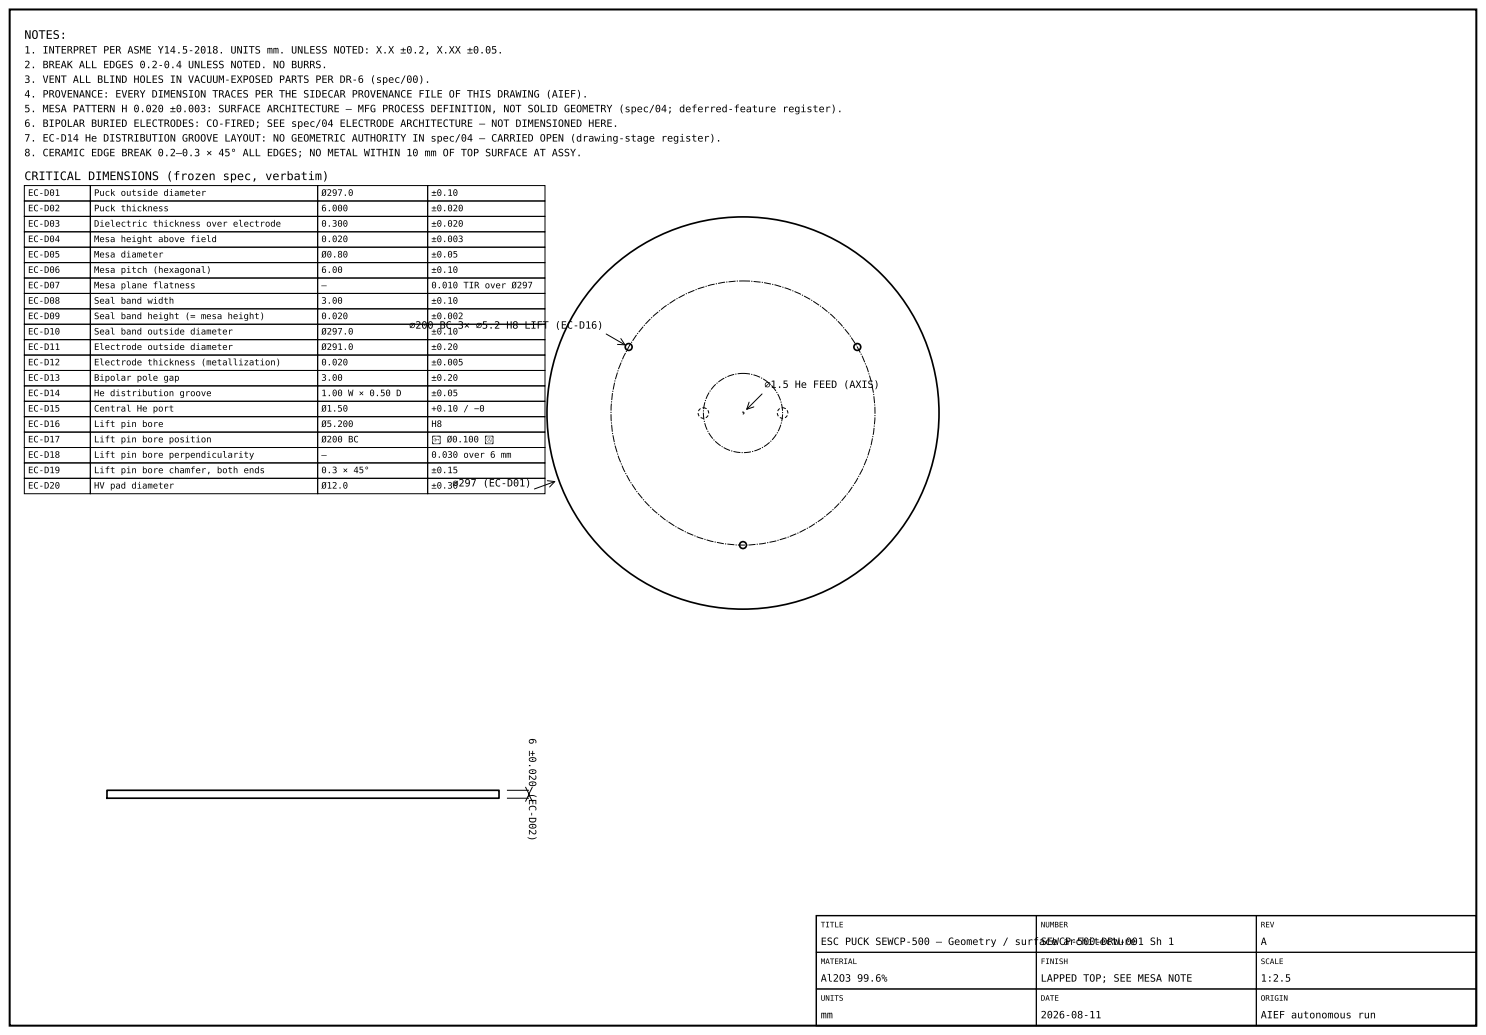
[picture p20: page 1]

NOTES:
1. INTERPRET PER ASME Y14.5-2018. UNITS mm. UNLESS NOTED: X.X ±0.2, X.XX ±0.05.
2. BREAK ALL EDGES 0.2-0.4 UNLESS NOTED. NO BURRS.
3. VENT ALL BLIND HOLES IN VACUUM-EXPOSED PARTS PER DR-6 (spec/00).
4. PROVENANCE: EVERY DIMENSION TRACES PER THE SIDECAR PROVENANCE FILE OF THIS DRAWING (AIEF).
5. MESA PATTERN H 0.020 ±0.003: SURFACE ARCHITECTURE — MFG PROCESS DEFINITION, NOT SOLID GEOMETRY (spec/04; deferred-feature register).
6. BIPOLAR BURIED ELECTRODES: CO-FIRED; SEE spec/04 ELECTRODE ARCHITECTURE — NOT DIMENSIONED HERE.
7. EC-D14 He DISTRIBUTION GROOVE LAYOUT: NO GEOMETRIC AUTHORITY IN spec/04 — CARRIED OPEN (drawing-stage register).
8. CERAMIC EDGE BREAK 0.2–0.3 × 45° ALL EDGES; NO METAL WITHIN 10 mm OF TOP SURFACE AT ASSY.

CRITICAL DIMENSIONS (frozen spec, verbatim)

EC-D01 | Puck outside diameter | Ø297.0 | ±0.10
EC-D02 | Puck thickness | 6.000 | ±0.020
EC-D03 | Dielectric thickness over electrode | 0.300 | ±0.020
EC-D04 | Mesa height above field | 0.020 | ±0.003
EC-D05 | Mesa diameter | Ø0.80 | ±0.05
EC-D06 | Mesa pitch (hexagonal) | 6.00 | ±0.10
EC-D07 | Mesa plane flatness | — | 0.010 TIR over Ø297

EC-D08 | Seal band width | 3.00 | ±0.10
EC-D09 | Seal band height (= mesa height) | 0.020 ⌀200 BC 3× ⌀5.2 H8 LIFT (EC-D16) | ±0.002
EC-D10 | Seal band outside diameter | Ø297.0 | ±0.10
EC-D11 | Electrode outside diameter | Ø291.0 | ±0.20
EC-D12 | Electrode thickness (metallization) | 0.020 | ±0.005
EC-D13 | Bipolar pole gap | 3.00 | ±0.20
EC-D14 | He distribution groove | 1.00 W × 0.50 D | ±0.05
EC-D15 | Central He port | Ø1.50 | +0.10 / −0

⌀1.5 He FEED (AXIS)

EC-D16 | Lift pin bore | Ø5.200 | H8
EC-D17 | Lift pin bore position | Ø200 BC | ⌖ Ø0.100 Ⓜ
EC-D18 | Lift pin bore perpendicularity | — | 0.030 over 6 mm

EC-D19 | Lift pin bore chamfer, both ends | 0.3 × 45° | ±0.15
EC-D20 | HV pad diameter | Ø12.0 | ⌀297 (EC-D01) ±0.30

TITLE ESC PUCK SEWCP-500 — Geometry / surface architecture | NUMBER SEWCP-500-DRW-001 Sh 1 | REV A

MATERIAL Al2O3 99.6% | FINISH LAPPED TOP; SEE MESA NOTE | SCALE 1:2.5

UNITS mm | DATE 2026-08-11 | ORIGIN AIEF autonomous run

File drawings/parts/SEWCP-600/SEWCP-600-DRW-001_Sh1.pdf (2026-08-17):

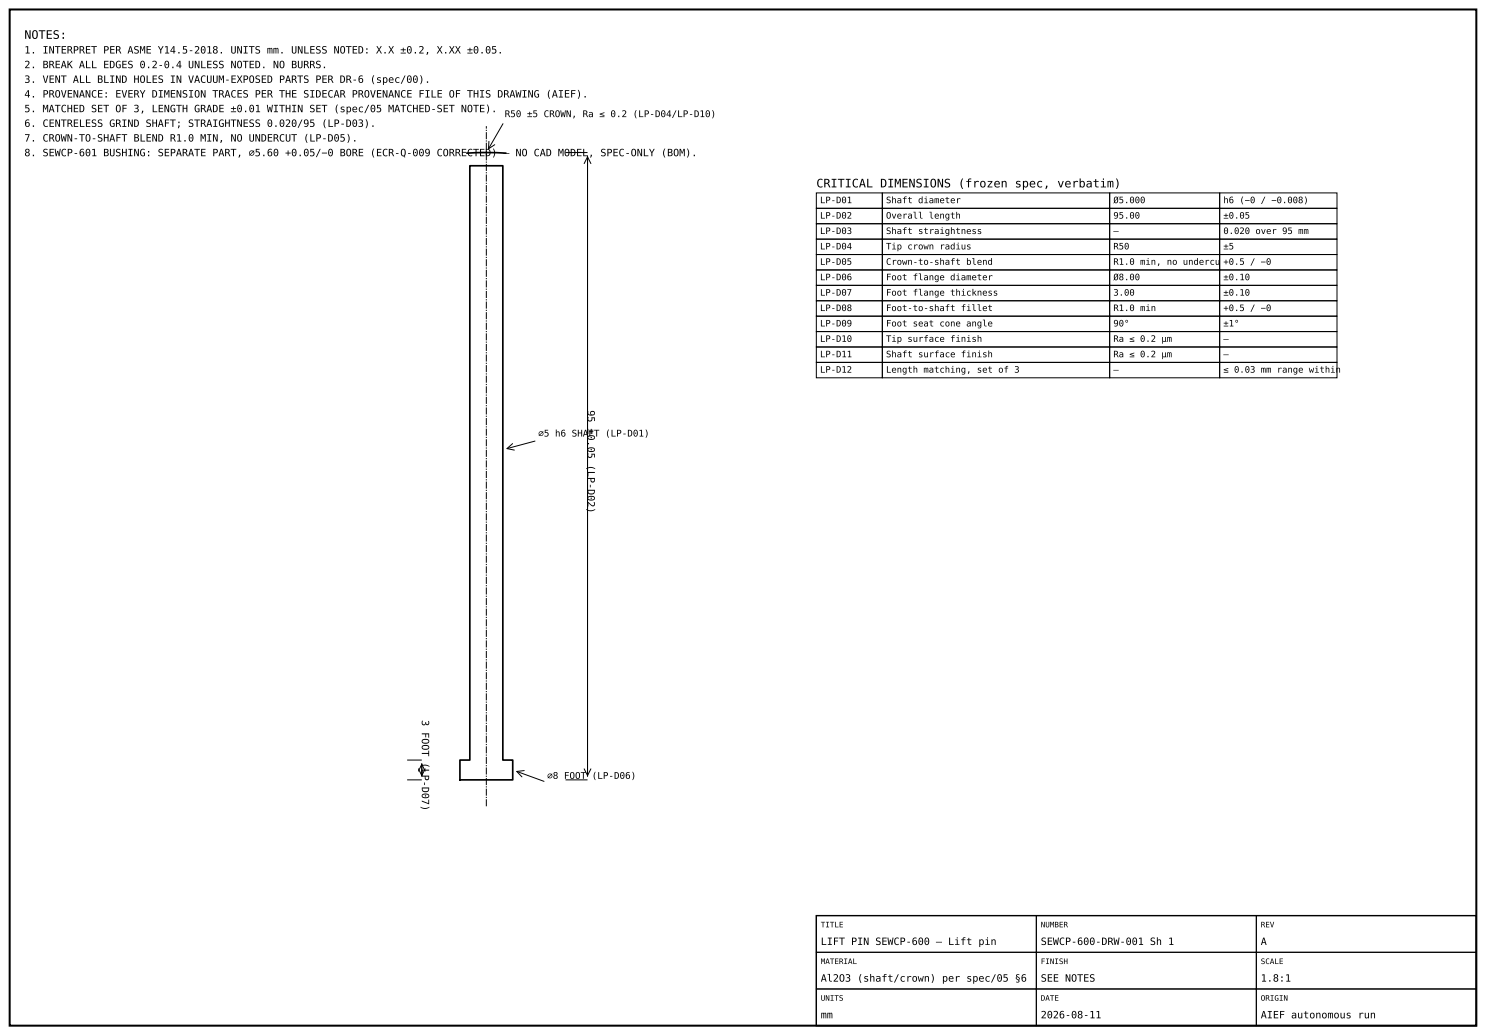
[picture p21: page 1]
3 FOOT (LP-D07); ⌀5 h6 SHAFT (LP-D01); ⌀8 FOOT (LP-D06)

NOTES:
1. INTERPRET PER ASME Y14.5-2018. UNITS mm. UNLESS NOTED: X.X ±0.2, X.XX ±0.05.
2. BREAK ALL EDGES 0.2-0.4 UNLESS NOTED. NO BURRS.
3. VENT ALL BLIND HOLES IN VACUUM-EXPOSED PARTS PER DR-6 (spec/00).
4. PROVENANCE: EVERY DIMENSION TRACES PER THE SIDECAR PROVENANCE FILE OF THIS DRAWING (AIEF).
5. MATCHED SET OF 3, LENGTH GRADE ±0.01 WITHIN SET (spec/05 MATCHED-SET NOTE).
6. CENTRELESS GRIND SHAFT; STRAIGHTNESS 0.020/95 (LP-D03).
7. CROWN-TO-SHAFT BLEND R1.0 MIN, NO UNDERCUT (LP-D05).
8. SEWCP-601 BUSHING: SEPARATE PART, ⌀5.60 +0.05/−0 BORE (ECR-Q-009 CORRECTED) — NO CAD MODEL, SPEC-ONLY (BOM).

R50 ±5 CROWN, Ra ≤ 0.2 (LP-D04/LP-D10)

CRITICAL DIMENSIONS (frozen spec, verbatim)

LP-D01 | Shaft diameter | Ø5.000 | h6 (−0 / −0.008)

LP-D02 | Overall length | 95.00 | ±0.05
LP-D03 | Shaft straightness | — | 0.020 over 95 mm

LP-D04 | Tip crown radius | R50 | ±5
LP-D05 | Crown-to-shaft blend | R1.0 min, no undercu | +0.5 / −0

LP-D06 | Foot flange diameter | Ø8.00 | ±0.10
LP-D07 | Foot flange thickness | 3.00 | ±0.10
LP-D08 | Foot-to-shaft fillet | R1.0 min | +0.5 / −0

LP-D09 | Foot seat cone angle | 90° | ±1°
LP-D10 | Tip surface finish | Ra ≤ 0.2 µm | —
LP-D11 | Shaft surface finish | Ra ≤ 0.2 µm | —
LP-D12 | Length matching, set of 3 | — | ≤ 0.03 mm range within

TITLE LIFT PIN SEWCP-600 — Lift pin | NUMBER SEWCP-600-DRW-001 Sh 1 | REV A

MATERIAL Al2O3 (shaft/crown) per spec/05 §6 | FINISH SEE NOTES | SCALE 1.8:1

UNITS mm | DATE 2026-08-11 | ORIGIN AIEF autonomous run

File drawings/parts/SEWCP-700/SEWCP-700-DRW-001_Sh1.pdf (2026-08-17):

## NOTES:

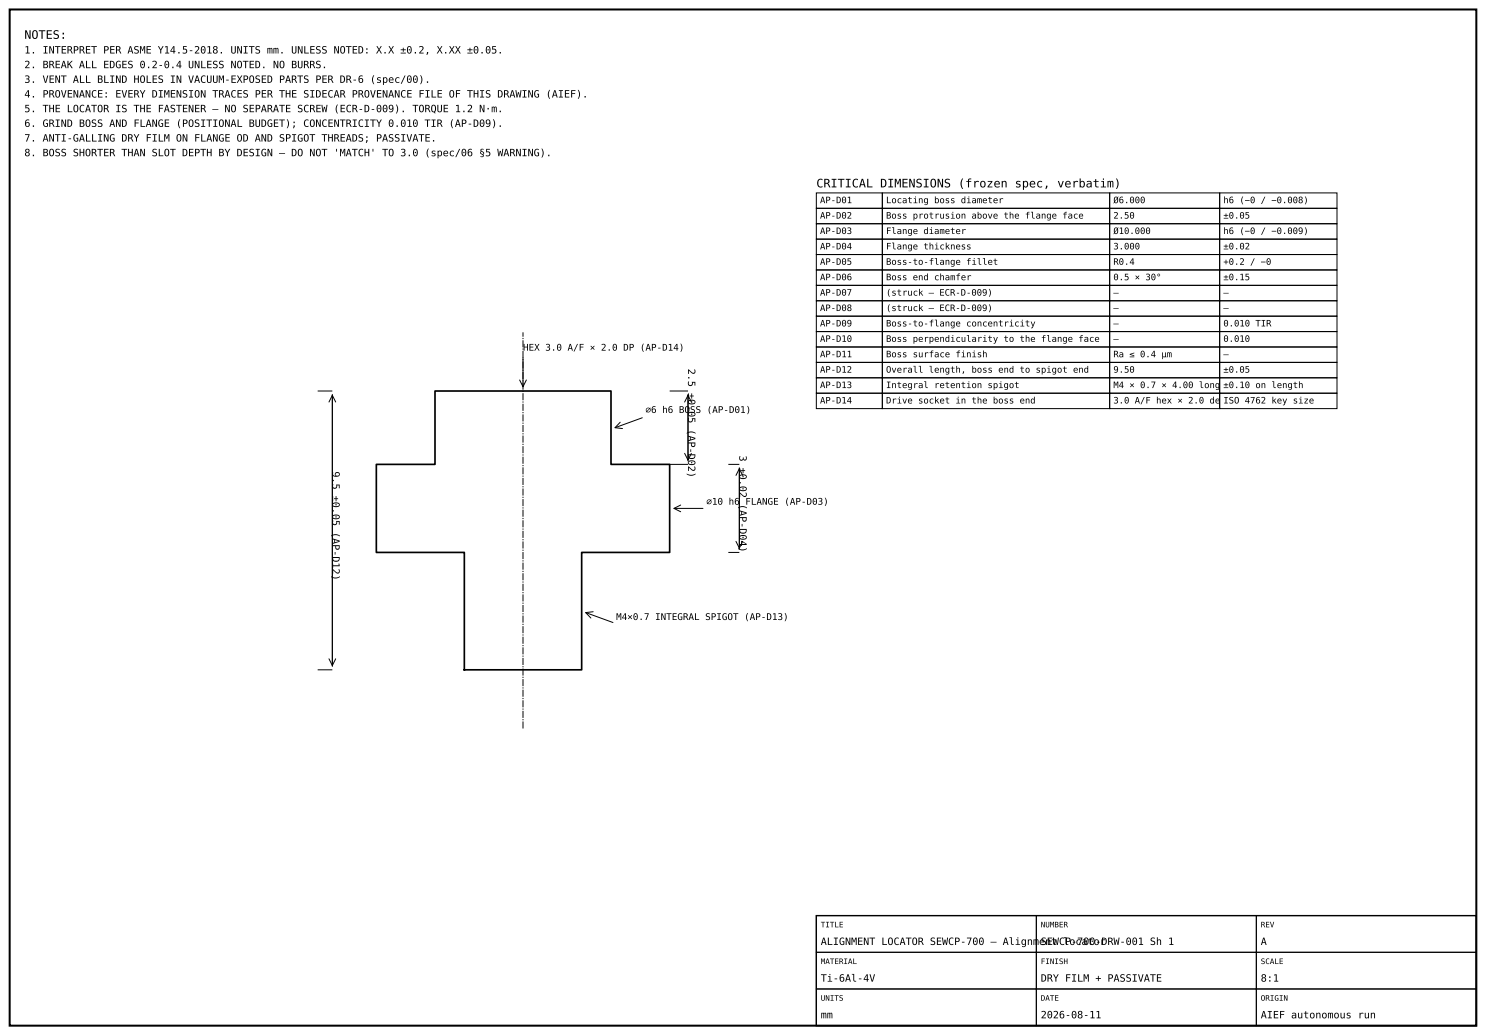
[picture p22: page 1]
⌀6 h6 BOSS (AP-D01); ⌀10 h6 FLANGE (AP-D03); Locating boss diameter; Boss protrusion above the flange face; Flange diameter; Flange thickness; Boss-to-flange fillet; Boss end chamfer; (struck — ECR-D-009); Boss-to-flange concentricity; 0.010 TIR; Boss perpendicularity to the flange face; Boss surface finish; Overall length, boss end to spigot end; Integral retention spigot; M4 × 0.7 × 4.00 long ±0.10 on length; Drive socket in the boss end; 3.0 A/F hex × 2.0 de ISO 4762 key size; REV; MATERIAL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

1. INTERPRET PER ASME Y14.5-2018. UNITS mm. UNLESS NOTED: X.X ±0.2, X.XX ±0.05.
2. BREAK ALL EDGES 0.2-0.4 UNLESS NOTED. NO BURRS.
3. VENT ALL BLIND HOLES IN VACUUM-EXPOSED PARTS PER DR-6 (spec/00).
4. PROVENANCE: EVERY DIMENSION TRACES PER THE SIDECAR PROVENANCE FILE OF THIS DRAWING (AIEF).
5. THE LOCATOR IS THE FASTENER — NO SEPARATE SCREW (ECR-D-009). TORQUE 1.2 N·m.
6. GRIND BOSS AND FLANGE (POSITIONAL BUDGET); CONCENTRICITY 0.010 TIR (AP-D09).
7. ANTI-GALLING DRY FILM ON FLANGE OD AND SPIGOT THREADS; PASSIVATE.
8. BOSS SHORTER THAN SLOT DEPTH BY DESIGN — DO NOT 'MATCH' TO 3.0 (spec/06 §5 WARNING).

CRITICAL DIMENSIONS (frozen spec, verbatim)

HEX 3.0 A/F × 2.0 DP (AP-D14)

M4×0.7 INTEGRAL SPIGOT (AP-D13)

TITLE
ALIGNMENT LOCATOR SEWCP-700 — Alignment locator

NUMBER
SEWCP-700-DRW-001 Sh 1

FINISH
DRY FILM + PASSIVATE

ORIGIN
AIEF autonomous run

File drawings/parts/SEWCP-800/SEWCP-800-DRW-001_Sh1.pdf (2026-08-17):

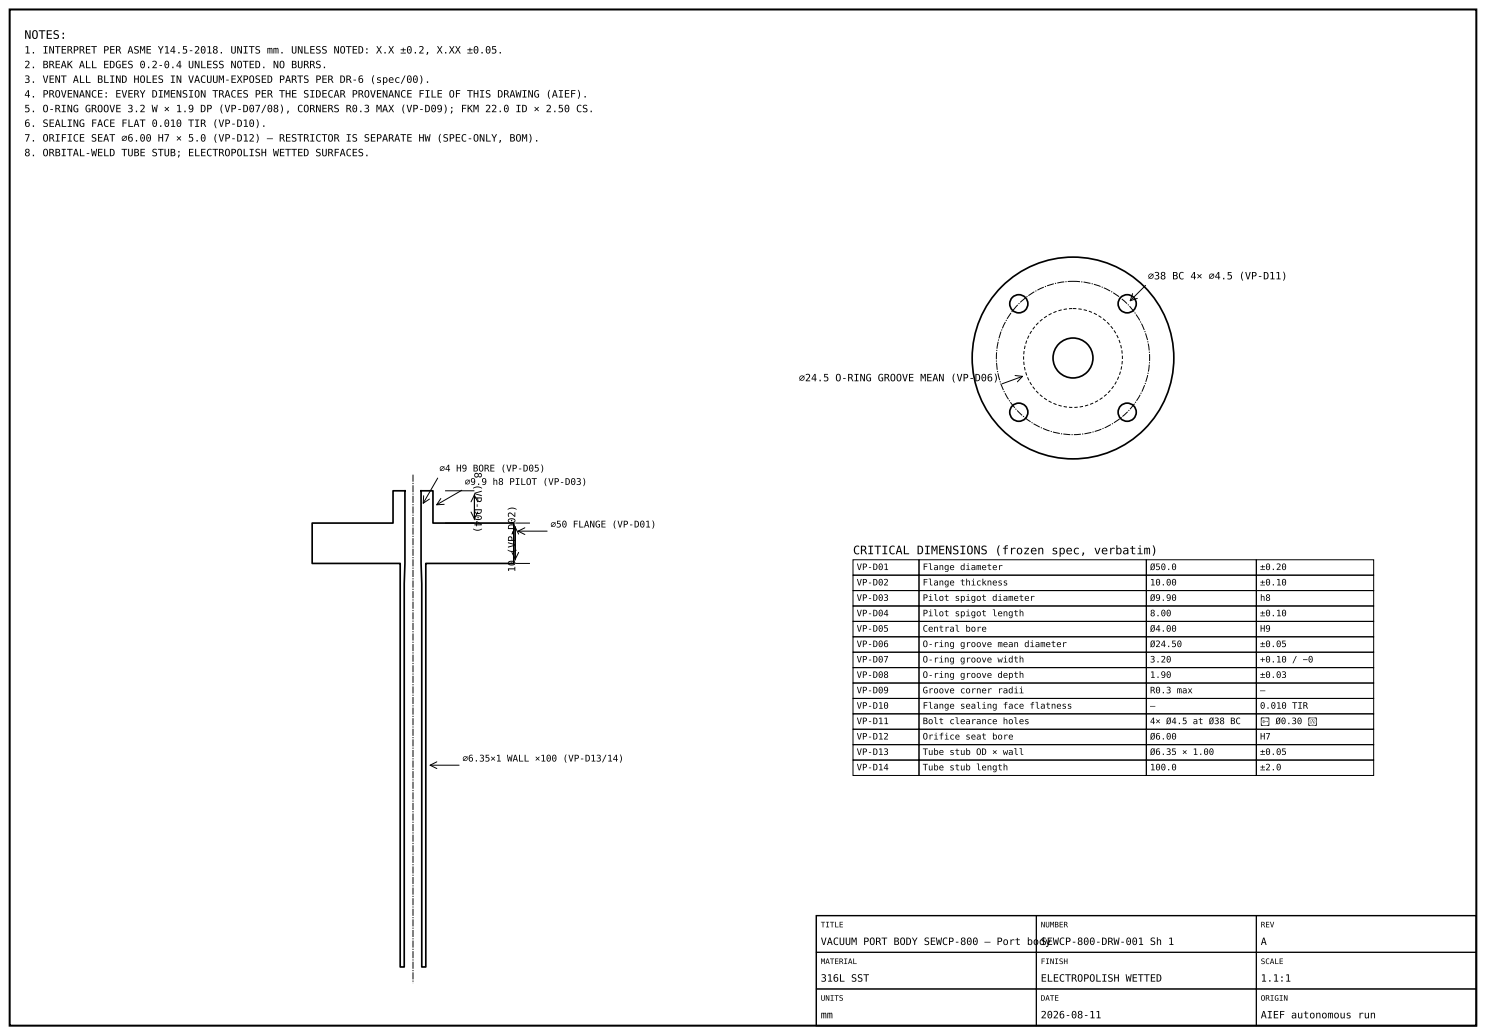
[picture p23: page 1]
8 (VP-D04) ⌀9.9 h8 PILOT (VP-D03); ⌀50 FLANGE (VP-D01); ⌀6.35×1 WALL ×100 (VP-D13/14); ⌀4 H9 BORE (VP-D05)

NOTES:
1. INTERPRET PER ASME Y14.5-2018. UNITS mm. UNLESS NOTED: X.X ±0.2, X.XX ±0.05.
2. BREAK ALL EDGES 0.2-0.4 UNLESS NOTED. NO BURRS.
3. VENT ALL BLIND HOLES IN VACUUM-EXPOSED PARTS PER DR-6 (spec/00).
4. PROVENANCE: EVERY DIMENSION TRACES PER THE SIDECAR PROVENANCE FILE OF THIS DRAWING (AIEF).
5. O-RING GROOVE 3.2 W × 1.9 DP (VP-D07/08), CORNERS R0.3 MAX (VP-D09); FKM 22.0 ID × 2.50 CS.
6. SEALING FACE FLAT 0.010 TIR (VP-D10).
7. ORIFICE SEAT ⌀6.00 H7 × 5.0 (VP-D12) — RESTRICTOR IS SEPARATE HW (SPEC-ONLY, BOM).
8. ORBITAL-WELD TUBE STUB; ELECTROPOLISH WETTED SURFACES.

⌀24.5 O-RING GROOVE MEAN (VP-D06)

CRITICAL DIMENSIONS (frozen spec, verbatim)

VP-D01 | Flange diameter | Ø50.0 | ±0.20
VP-D02 | Flange thickness | 10.00 | ±0.10
VP-D03 | Pilot spigot diameter | Ø9.90 | h8
VP-D04 | Pilot spigot length | 8.00 | ±0.10
VP-D05 | Central bore | Ø4.00 | H9
VP-D06 | O-ring groove mean diameter | Ø24.50 | ±0.05
VP-D07 | O-ring groove width | 3.20 | +0.10 / −0

VP-D08 | O-ring groove depth | 1.90 | ±0.03
VP-D09 | Groove corner radii | R0.3 max | —
VP-D10 | Flange sealing face flatness | — | 0.010 TIR

VP-D11 | Bolt clearance holes | 4× Ø4.5 at Ø38 BC | ⌖ Ø0.30 Ⓜ

VP-D12 | Orifice seat bore | Ø6.00 | H7
VP-D13 | Tube stub OD × wall | Ø6.35 × 1.00 | ±0.05
VP-D14 | Tube stub length | 100.0 | ±2.0

TITLE VACUUM PORT BODY SEWCP-800 — Port body | NUMBER SEWCP-800-DRW-001 Sh 1 | REV A

MATERIAL 316L SST | FINISH ELECTROPOLISH WETTED | SCALE 1.1:1

UNITS mm | DATE 2026-08-11 | ORIGIN AIEF autonomous run

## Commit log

2026-08-07 Initialize repository and establish Release 0.1 infrastructure
    Sets up version control and repository structure for the SEWCP program.
    Infrastructure only. No engineering content was created, modified,
    reviewed or decided. No CAD work performed. No implementation
    instructions authored. The frozen specification baseline is unaltered.
    Structure:
    spec/ frozen engineering baseline, Volumes 00-09
    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
2026-08-07 Release 0.3: Generate AIEF Stage 1 and Stage 3 repository framework
2026-08-07 Release 0.5: Generate AIEF Stage 4 adapter layer and Claude Code host binding
2026-08-07 Release 0.6: Add Mechanical CAD Engineer to the mechanical profile
2026-08-07 Add compiler_stage state field and synchronize repository state
    AIEF-AMD-007 (AMD-15). The cold-start acceptance test recovered every
    required fact from repository artifacts except compiler stage completion,
    which was obtainable only by inspecting the filesystem for the presence
    or absence of core/templates/, core/validation/ and core/MANIFEST.lock.
    That is inference. A fact recoverable only by deduction can be deduced
    wrongly, so it is now declared.
    compiler_stage is added to SCH-state.required_fields and to
    tpl-current-state.required_sections, with a new acceptance condition:
    compiler stage declares complete and outstanding stages explicitly,
    never by inference. Because the field is requi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
2026-08-08 Release 0.8: Generate AIEF Stage 2 template layer and dispose QA-001 findings under AIEF-AMD-008
2026-08-08 Release 0.10: Generate AIEF Stage 5 validation layer and file independent verification VER-003
2026-08-08 File Stage 6 pre-flight requirements determination for CMP-BLOCK-004 and CMP-BLOCK-005
2026-08-08 Dispose Stage 6 pre-flight open questions under AIEF-AMD-010 and file independent verification VER-004
2026-08-09 Close G-1: a supersedes_seal that is not a mapping is no longer read as no seal block
    The confirmatory verification of the F-1/F-2 closure returned NOT CONFIRMED with
    one MAJOR blocker, and it was right. This is the same two-facts-one-value defect
    a fourth time, one level below the one F-1 closed.
    G-1, MAJOR. ResultRecord.supersedes_seal coerces anything that is not a mapping
    to {}, and graph.seal_declared_block read bool(result.supersedes_seal). So {}
    meant "no block" and "a block that did not parse as a mapping", and both the F-1
    and the F-2 guard - built to close exactly this shape of defect one level up -
    skipped the malformed case in silence.
    It needs no exotic syntax. The sequence fo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
2026-08-09 Declare LC-M04-EXIT acceptance criteria C1-C7 on the owner's decision
    The gate has been ACTIVE - BLOCKED with no criteria recorded: GATES.md said
    "None recorded yet - a project-manager action", and project-manager is
    UNASSIGNED. Phase 9 of the current mission requires running "the exact
    acceptance criteria", so with none declared any CLEARED verdict would have been
    unfalsifiable.
    The framework delegates the content of these criteria to this file
    (LC-M04_implementation.md, PROFILE.md) and fixes only their form: binary and
    evidence-based, LAW-03. The human owner declared them this session, option C.
    Recorded here rather than authored: every criterion traces to a recorded source
    and none state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
2026-08-09 ECR-D-001 disposition A: SEWCP-700 governs the alignment pin interface
    The alignment-pin interface was specified two mutually exclusive ways. SEWCP-200
    defined a Ø6.000 H7 press-fit dowel bore; SEWCP-700 defined a screw-retained
    shouldered locator seated in a Ø12.0 H7 x 3.0 counterbore. As written the
    specification could not be assembled at all: SEWCP-200 directed a 5.0 mm
    protrusion into mating slots that are 3.00 mm deep, which bottoms by 2.0 mm and
    holds the mating faces apart - destroying the thermal choke contact, the
    flatness budget and the joint preload at once.
    Human owner ruled Option A: SEWCP-700 governs. It carries the quantified
    derivation - thermal interference loss, wear aga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
2026-08-09 Strike the unauthorised M4 tap depth; move the determination to ECR-D-007
    VER-008 R10(a): CP-D09a and CP-D10a carried "M4 x 0.7, 8.0 deep". The approved
    Option A text says "M4 tapped hole" with no depth, and SEWCP-700 - the governing
    volume - specifies the fastener as M4 x 10 SHCS and states no plate-side tap
    depth anywhere. I chose 8.0 mm, froze it into a registered artifact, and then
    certified in APR-017 that no engineering value had been set by an implementing
    agent.
    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
2026-08-09 Repair VER-010 round-3 findings: stop relocating defects instead of removing them
    Round 3 returned FAIL on three clerical blockers, and two were defects round 2
    had already raised. I had moved them rather than removed them.
    V1 - the ECR's approval: field named APR-017 and labelled it "# LIVE". APR-018
    had voided APR-017. Round 2 raised exactly this against APR-016; the repair
    pointed the field at the next approval to be voided and re-asserted liveness by
    hand. The field now names APR-018 as terminal, records the chain
    APR-016 -> APR-017 -> APR-018, and ASSERTS NO LIVENESS AT ALL: it instructs the
    reader to determine liveness by recomputing the terminal approval's subject_hash.
    A claim that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
2026-08-09 Record ECR-D-001 engineering as verified; open OI-V-11 for the C6 evidence defect
    Human-owner ruling S-2026-08-09-14, option 2: accept ECR-D-001's engineering as
    independently verified and proceed to the remaining Design Authority decisions in
    parallel, rather than queueing them behind the verification report's bookkeeping.
    Two facts, recorded separately because they differ. The engineering is verified -
    four cold rounds re-derived it from repository bytes, and round 4 returned
    W9 RECORD ACCURATE: PASS with the controls byte-identical, the approval chain
    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
2026-08-09 ECR-D-002 disposition A: coolant channel depth 8.00 -> 6.00 so the Z stack closes
    The Cooling Plate's through-thickness arithmetic did not close. The channel is
    machined into the bottom face and closed by an FSW lid, so top face downward:
    CP-D07 wall 8.00 + CP-D06 depth 8.00 + CP-D08 lid 6.00 = 22.00, against CP-D02
    overall thickness 20.000 +/-0.030. Over by 2.00 mm.
    CP-D02 governs on the record: 20.000 is corroborated six times - the dimension
    row, requirement CP-10 verified by micrometer at 8 points, the ICD assembly
    diagram Z = 20.0, the ICD tolerance-allocation budget, the inspection plan and
    the mass estimate - and it is the only Critical term. The three sub-dimensions
    are Medium and s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
2026-08-10 Disposition nine ECRs against the frozen spec; put the gate under standing checks
    C1-C5 and C7 pass on computed evidence. C6 fails: both independent rounds
    declare NOT CLEARED, so LC-M04-EXIT is not passed and CAD is not authorised.
    Nine dispositions, each ruled by the human owner across four decision pauses:
    D-001 residual, D-002 completion, D-003, D-004, D-007, D-008, D-009, D-010,
    D-011. Applied to seven spec artifacts, bound by APR-020..APR-027,
    re-registered, aggregate recomputed.
    Five ECR records did not exist. C3 and C4 had been gate criteria for a dozen
    sessions with no artifact to evaluate, and C7 was undecidable rather than
    unsatisfied because ECR-D-006 had no record to read. No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
2026-08-10 Close LC-M04-EXIT C6: rule and seal the verification-supersession relation
    C1-C7 all PASS. python -m aief_gate exits 0 and prints LC-M04 CAD-READY: YES.
    CAD is authorised to begin. No spec/** artifact changed - the frozen set is
    byte-identical to 5e7ac74 and its DC-2 aggregate is unchanged.
    C6 was unreachable, not unsatisfied. VER-016 demonstrated that an adverse
    report is permanent, so VER-015's NOT CLEARED blocked the gate for as long as
    the file existed, and named the remedy in terms: an instrument change to C6,
    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
    [SEWCP-200.csv]
2026-08-11 Build and verify the SEWCP-200 CAD increments through the agent-driven pipeline
    Three requirement packages executed in live Fusion via the general-purpose
    CAD layer (orchestrator, domain agents, design solution, file-queue bridge,
    independent verifiers), each verified from observed model state:
    - REQ-001 base and datums: 32/32 PASS after the observation layer was ruled
    to report the persisted design name (Option 1), never the versioned
    display string.
    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
2026-08-11 Design and build the SEWCP-200 below-face features through the agent pipeline
    REQ-004: the mechanical agent designs 44 axial holes and 32 slotted
    outlines (ring taps, locator counterbores and retention taps on both
    faces, central He bore, vacuum taps, lift-pin bores and bushing
    counterbores, HV bores, RF taps, RTD ports and retainer taps, 16 choke
    slots and their CP-D26 counterbores) from the parameter master and spec
    clocking, as fifteen pattern groups. Verified 20/20 from observed Fusion
    state on attempt 1 of the second run; the first run is retained as the
    honest FAIL record of the over-constrained central-circle defect, fixed
    at the automation layer alongside the multi-profile cut select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
2026-08-11 Complete the SEWCP-200 CAD model: DR-6 vents, material, mass; automate the Fusion session lifecycle
    REQ-005 closes the model scope: the design agent routes the three DR-6
    cross-vents (to the He bore, the lift-pin bore chord, and the OD - each
    the shortest safe path, alternatives recorded), 6061-T6 is assigned, and
    CP-15 verifies in-model at an observed 3.995 kg. PASS 19/19 on attempt 1.
    Lifecycle automation at the bridge: a hot-reloadable operation extension
    (bridge_ops_ext.py, mtime-reloaded per command) ends add-in restarts for
    future operations; save_document and revert_document ops plus the
    orchestrator's save-on-pass and the revert CLI make verified-state
    persistence and failed-increme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
2026-08-11 Build and verify SEWCP-700 through the autonomous loop; export deliverables externally
    Next component selected by dependency ranking: the SEWCP-700 integral
    shouldered locator screw (ECR-D-009) - smallest fully-ruled volume,
    closing live interfaces against the verified SEWCP-200 counterbores.
    Agent-designed from spec/06: M4 spigot, O10.000 h6 flange, O6.000 h6
    boss, 3.0 A/F hex socket via the new generic profile_cut form, Ti-6Al-4V,
    AP-D12 closed by the derived ap_len. PASS 25/25 from observed state.
    The full failure loop ran without human Fusion interaction: three
    defects (setup-time material on an empty design, cross-agent plane
    ordering in the disc form, join-stack extent semantics in th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
2026-08-11 Autonomous loop: SEWCP-600, SEWCP-1000 and SEWCP-800 designed, built, verified, exported
    Three components through the full loop without human Fusion interaction:
    lift pin (alumina, PASS 18/18), sensor retainer (first rectangular body
    via profile_cut new_body, PASS 17/17 after an honest feature-count fix),
    and the 316L vacuum port body (PASS 20/20 first attempt). Architecture
    gains, all generic: material requirement kind owned by the DFM agent,
    profile_cut new_body/join, ring_groove form with area-ranked profile
    selection in the hot-reloaded extrude override - the deterministic way
    to cut a face-seal groove. Evidence in cad/runs/; STEP/STL exported
    under D:\AIEF_CAD_OUTPUT\SEWCP\.
2026-08-11 Autonomous loop: SEWCP-901 strap and SEWCP-902 saddle built, verified, exported
    The formed RF strap models through the new generic swept_strip form -
    side path offset by the routing layer, tessellated, extruded to width -
    with the S-compliance derivation recorded (dev 180 closed exactly).
    Saddle height derived 8.0 - 0.5 strap. Verifier extent checks now skip
    sketches on derived planes, whose normal is unchartable. Ext extrude
    error diagnostics added after a transient post-revert lookup miss.
2026-08-11 Autonomous loop: SEWCP-400 support ring built, verified, exported
    The alumina I-section ring through ring_groove annular-band forms
    (new_body/join), two flange hole circuits, kinematic slots at 60/180/300
    receiving the plate locators. Two honest findings recorded: SR-D16 as
    tabulated is degenerate on this part (envelope exceeds the flange band
    both sides - removes the datum face) and is carried as a drawing-stage
    clarification, candidate ECR-Q, not silently reinterpreted; the spec
    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
2026-08-11 Spiral routing for the heater grooves: exact keep-out projection, arc-chain compression
    route_spiral generates the two-zone Archimedean grooves with exact
    tangential keep-out deflection (samples projected onto the clearance
    circle, arc-following between deflected samples, densify-and-reproject
    closure) and compresses the audited polyline to a drawable arc chain
    via greedy circumcircle fitting at 0.05 mm - outer spiral 175 arcs at
    7855 mm and inner 44 arcs at 2597 mm, matching the spec 2.2 developed
    lengths exactly. spiral_groove agent form added; SEWCP-300 package
    authored (spirals, slots, M5 circuit, bores, He O-ring groove, RTD).
    Live execution is currently blocked behind the first oversi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
2026-08-11 Complete the defined SEWCP CAD design: all nine component volumes verified; system interfaces 12/12
    The autonomous loop finished the design stream: heater plate PASS 24/24
    with both routed heater spirals (arc-fitted, keep-outs dodged per
    ECR-D-011, developed lengths matching section 2.2 exactly) and the ESC
    puck PASS 18/18 (co-fired process layers recorded as drawing/process
    callouts). Outline welding fixes profile closure for arc-fitted chains.
    System-level verification computes 12/12 cross-component interface
    checks from recorded observed evidence - locator fits, slot engagement,
    pin guidance, port pilot, bolt-circle identity, the HP blind-tap
    ligament, and the Vol 00 Z-stack closing at ex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
2026-08-11 Post-geometry completion: assembly built and verified, drawing set, BOM, final system verification 15/15
    Assembly: generic bridge vocabulary (documents, occurrences, placement,
    observation), src/aief_cad/assembly.py runner/verifier; SEWCP-000 master
    assembly from the ten saved verified designs, 19 occurrences verified
    from observed state and saved. SEWCP-901 re-issued in installed form
    (free-state S could not mate the CP-IF-8 land); re-verified 15/15 and
    re-exported. Fusion tree cleaned: blank-shell orphan and superseded
    lineages renamed out of the operational namespace.
    Drawings: src/aief_draw (mandatory dimension provenance, SVG+PDF),
    drawings/defs definitions; 10 part drawings incl. SEWC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
2026-08-11 Document-creation lifecycle repair: identity without persistence, save only on verified PASS, failure disposition
    Root cause traced from run evidence: the ext rename_component op
    first-saved never-saved documents at setup (op 3, before geometry), and
    no failure path disposed of documents - failed or interrupted runs left
    blank/interim designs saved (the ZZ-ORPHAN-BLANK-SHELL and
    ZZ-INTERIM-ATTEMPT class), and name collisions then produced duplicate
    lineages.
    Repair at the owning layers: rename_component now binds an
    aief:intended_name design attribute without saving; the shell and ext
    identity helpers fall back to the intended name so adoption, ACC-NAME
    observation and save_document see ide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
2026-08-11 Bridge resumed: orphans deleted, lifecycle validated live, CP lineage re-homed, assembly and lift pin finalized
    With the bridge re-armed: the two failure-artifact ZZ designs were
    deleted through the guarded delete_data_file op; a deliberately failing
    run validated the lifecycle fix live (geometry built, verification
    failed, document discarded - saved-design census identical before and
    after); OI-CAD-01 closed by re-assigning the lift pin to 99.8% alumina
    (observed 7.63 g), saving and re-exporting; OI-CAD-02 closed by
    re-homing the verified CP content to a fresh lineage (save_as_new_lineage
    op) after proving the old lineage's cloud reference-derivative durably
    served v4 content to inserts acr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
2026-08-11 Delegated-authority engineering resolution: ECR-D-013/Q-011/Q-012 and the coolant path dispositioned, implemented, verified
    Under the owner's written delegation (mission 2026-08-11 s1), all four
    carried engineering items were resolved with full decision provenance
    (.ai/project/decisions/DECISIONS_S-2026-08-11-05.md) and the approvals
    APR-029..APR-032, each recorded as owner-delegated authority exercised
    by Claude - never as human approval. FROZEN re-registered twice with the
    DC-2 aggregate recomputed; both spec chains resolve; gate computes
    LC-M04 CAD-READY: YES on C1..C7.
    ECR-D-013 -> A: strap holes tap-coincident (29.94 centres); SEWCP-901
    rebuilt PASS and re-exported. ECR-Q-012 -> plate-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
2026-08-11 Release-readiness audit: ECR-D-006 and ECR-D-014 dispositioned, five defects found, no CAD changed
    Audit of the baseline at baf843a. NO VERIFIED CAD GEOMETRY WAS MODIFIED; every
    spec/** digest is unchanged. The incoming baseline reported "2 known pre-existing
    ECR-D-006 failures". Both are gone, and three further defects were found beneath
    them.
    ECR-D-006 was two defects, and only one was on record. The AIEF-AMD-014 change
    set had been applied with every record of its authority omitted: APR-014 and
    APR-015 were never filed, the manifest row was never re-registered, and
    AIEF-AMD-014 itself was never added to the registry under the AMD-21 criterion
    its own Blast Radius declares. check_v24 name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
2026-08-12 Stage 6 canonical closeout: B2a proven, OQ-14 closed, ledger genesis to active
    The canonical Compiler Stage 6 emission was performed 2026-08-12 under the
    human owner's OQ-14 authorization of 2026-08-11 (DECISIONS_S-2026-08-11-06
    DEC-10, PRECEDENCE rank 1). It wrote exactly its two declared outputs -
    .ai/core/MANIFEST.lock and BINDING.core_digest_pin - and nothing else. No CAD,
    spec, drawing, BOM or parameter artifact was touched, so the owner's condition
    "without changing verified CAD" holds on the change set itself.
    B2a executes for the first time in this repository's history and PASSES. It was
    recomputed independently at boot from the AIEF-AMD-010 AMD-25/27 and
    AIEF-AMD-015 AMD-54/55 text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
2026-08-17 Public release preparation: licence ratified, deliverables brought into the repository, independent QA findings repaired, ECR-D-016 raised
    C-4 is closed. LICENSE is MIT AND CC-BY-4.0 with the boundary declared by path
    and exhaustive over the tracked tree, both full texts embedded. Third-party
    licences were read from each installed distribution's own metadata rather than
    assumed; nothing in the set is copyleft. The decisive constraint was technical:
    no per-file notice may be added here, because ~100 artifacts are DC-1-registered
    and a header would void an approval under LAW-10 clause 2 and halt boot step
    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
    [SEWCP-000_BOM_RevA.csv, SEWCP-000_MASTER_ASSEMBLY.step, SEWCP-1000_RETAINER.step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]
2026-08-17 Second independent QA round: canonical-path enforcement repaired, four false statements withdrawn, clone reproducibility fixed
    The fresh cold round required after S-2026-08-17-01 ran against the pushed
    tree and returned NOT CLEARED with 22 findings. It confirmed the tree did not
    move under it, which is the OI-P-04 mitigation working. This is what it found.
    FIND-1, MAJOR. The ECR-D-014 ruling was enforced only on the PREVIEW path. A
    mutation skipping the cap check when `canonical` is true survived all 846
    tests, and the canonical build then wrote core/MANIFEST.lock and the BINDING
    pin with a 249-token prefix against a cap of 200. The cause was structural: no
    test in this repository had ever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
2026-08-17 Third independent QA round: enforcement condition discharged, register staleness cured procedurally, OI-C-10 arrives
    The third cold round declared ECR-D-014's ENFORCEMENT condition FULLY
    DISCHARGED and said it should not be re-audited. It applied the four required
    mutations and eleven further ones - six that the previous round had not tried,
    including deleting the post-condition, truncating inside boot_read_prefix so
    both derivations agree on a wrong region, returning before the post-condition,
    clamping instead of raising, comparing the record to itself, and an exploit of
    the stub probe's leniency - and all fifteen die. It also confirmed that
    _emit_once(canonical=True) cannot reach a canonic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
2026-08-17 Add portfolio documentation set and rewrite README for a general reader
    Presentation pass over the released state at v0.11.0 (f8ff028). No
    engineering artifact is created, modified or deleted: spec/**, src/**,
    tests/**, cad/**, drawings/**, analysis/**, framework/**, .ai/**,
    params/** and releases/** are untouched, and no Fusion document was
    opened. The only tracked file modified is README.md; everything else is
    new under docs/.
    Every figure published was recomputed during the pass rather than
    carried over from a prior summary. Verified: gate LC-M04-EXIT C1-C7,
    clearance, 105 parameters, approval chains, 61 deliverables both
    directions, registers, B2a 75/75, 19 assembly occurrences, 12/12
    i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
2026-08-17 Supersede R-030 with R-031 and close the portfolio governance gap
    The portfolio pass rewrote README.md, which R-030 pinned by DC-1. The
    record went STALE and X-06 - the drift detector - failed. That is the
    mechanism working, and EXECUTION_ARCHITECTURE.md section 6.1 states the
    answer in one sentence: correction is by supersession, never by
    mutation.
    R-031 republishes every pin against the finished tree and seals R-030 at
    the DC-1 it now stands at. R-030 receives its closing edit - status
    SUPERSEDED, superseded_by R-031 - and nothing else. T-009 declares
    produces: R-031 with a write path to it, which X-09 mode 1 requires.
    Ledger L-0000007 and HEAD carry the LAW-09 close.
    X-06 PASS. The suit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
2026-08-18 Reopen DEC-21 and authorise the publication-safety history sanitization
    The owner reopened DEC-21 after an independent public-release review measured its
    factual basis and found it wrong in both halves: the occurrence count is 52 in the
    run records and not 41, and the account name is neither already present in the commit
    history nor already public. Disposition B - sanitize before publication.
    ECR-D-018 records the defect and the approved transformation: replace only the local
    account-name segment with the neutral placeholder, preserving separator form and every
    other byte. No traceback structure, exception, module name, line number, timestamp,
    run id or Fusion build identifier is altered. N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
2026-08-18 Sanitize the local account name from history and close S-2026-08-18-02
    Reachable history was rewritten under ECR-D-018 and the owner's rank-1 override
    recorded at APR-039: the local Windows account-name segment is replaced by the
    neutral placeholder <user> in 53 occurrences across 11 blobs and 25 commits, with
    each occurrence's separator form preserved verbatim.
    Measured, not asserted. Of 54 commits, 29 are unchanged and 25 rewritten, with
    0 author-identity, 0 committer-identity, 0 timestamp and 0 commit-message
    mismatches, and exactly 11 paths carrying any content difference. For each of the
    ten run records the JSON structure, run id, timestamps, exception type and
    message, traceback frame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
